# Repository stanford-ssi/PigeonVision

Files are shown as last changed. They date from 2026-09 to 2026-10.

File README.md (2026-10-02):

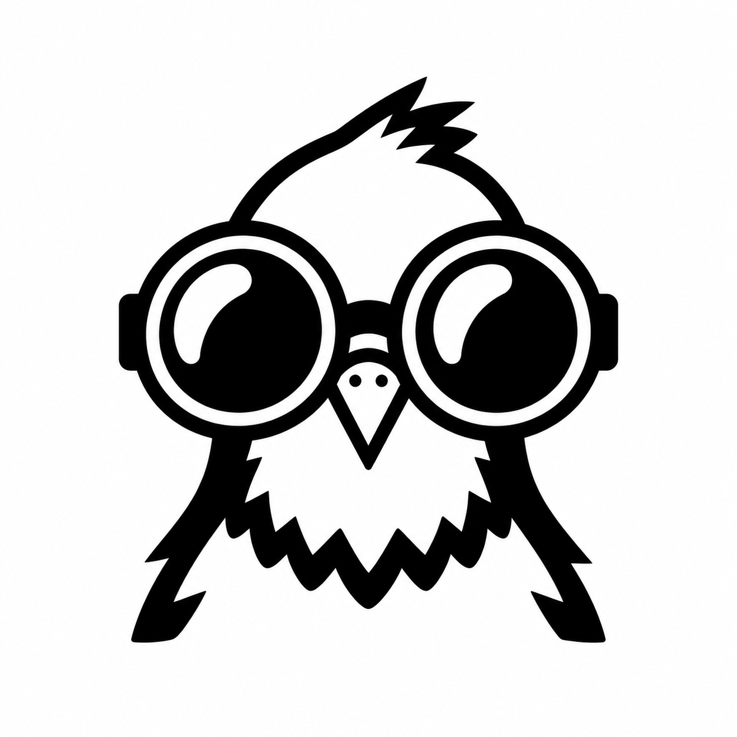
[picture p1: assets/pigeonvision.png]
Pigeon wearing two fisheye camera lenses


# PigeonVision

Video downlink for Stanford SSI's IREC rocket. Two fisheye cameras record the flight and send video to the ground for stitching and viewing.

Try the [flight demo](https://stanford-ssi.github.io/PigeonVision/) to see the camera views and stitched panorama.

**Cur Plan:** two IMX900 cameras at 30 fps, one CM5 and a custom RP2350B transmitter over PV-SPI. E200 remains the fallback. A ground SDR and Linux PC receive and stitch the video. Target: 10,000 ft AGL, 6-inch airframe, 0.5 W average PA output.

- [Hardware](hardware/README.md): system diagram, carrier and RF frontend.
- [Software](software/README.md): flight and ground tasks.
- [Link budget](calculations/link-budget.xlsx): RF and video bitrate calculations.
- [Simulator](docs/README.md): camera views, flight playback and local setup.

**Next:** test autonomous startup and sensor telemetry, then RF. Continue carrier design in parallel.

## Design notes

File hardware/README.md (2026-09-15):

# Hardware

System block diagram

[Edit in draw.io](system.drawio)

| Assembly | Job |
| --- | --- |
| [Carrier](carrier/README.md) | CM5, power, cameras, sensors and service connections. |
| [RF frontend](rf-frontend/README.md) | Attenuation, driver, PA and output filter. |
| Camera adapters, two copies | FRAMOS PixelMate-to-MC50 boards and cables; purchased parts preferred. |
| Flight E200 | DVB-S2 transmitter, mounted above the carrier and connected by Ethernet and SMA coax. |
| Ground E200 | RF receiver connected to the Linux PC over Ethernet. |

**Cur Plan:** KiCad carrier and RF boards, purchased CM5, radios and camera adapters.

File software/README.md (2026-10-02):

# PigeonVision software

The CM5 bench captures both colour IMX900 cameras, records their original video,
and streams to the Mac's interactive A/B and panorama viewer. It uses the official
CM5 IO board, FRAMOS drivers, Ethernet from the Pi, and software x264 encoding.
The Mac currently reaches the LAN over Wi-Fi.

Full 2064×1552 output approached dual 30 fps in short cached-buffer trials; a
later 180-second run still logged five queue drops. The panorama uses measured
lens fits with **nominal** opposed-camera alignment. One-hour performance,
held-out seam accuracy, colour accuracy and exposure synchronization remain
unqualified. See the [bench evidence](bench-notes/2026-09-25.md).

Native SPI is the baseline CM5-to-RP2350B link. The bench uses a Pimoroni Pico
Plus 2 development board; the flight transmitter will use the RP2350B chip.
With a fan, the two-minute test
reached **29.99 fps per camera and 9 Mb/s TS**, with matching Pico counts and
CRC. CPU averaged 61.4%; maximum temperature was 56.75°C. Each camera had one
66.7 ms interval after warm-up. Keep `pv spi` for patterns and file tests.
See [SPI results and setup](flight/spi.md). RF remains untested.

The native service also supports autonomous CM5 acquisition: unique sessions,
independent camera/sensor/UART workers, bounded telemetry and status reporting.
The carrier sensor and UART backends are implemented; their physical wiring,
measurements and FC firmware acceptance remain unverified. Carrier power/reset
sequencing and AFE/LO/PA control have no mapped implementation.

The [startup comparison](bench-notes/flight-startup.json) held dual 30 fps for
two minutes with simulated sensor telemetry over UDP. All 7,201 encoded frames
and 28,206 sensor samples arrived. The new RP2350B startup still needs a SPI run.

## Start here

| Guide | Covers |
| --- | --- |
| [Native capture](flight/README.md) | C++20/libcamera/x264 build, buffers, recording and transport |
| [CM5 → Pico SPI](flight/spi.md) | PV-SPI wiring, sender, backpressure, evidence and viewer copy |
| [Ground app](python/pigeonvision/ground/README.md) | Viewing, replay, E200 receive setup, recording and colour controls |
| [Calibration](calibration/README.md) | Board collection, lens fitting and nominal preview |
| [Shared interfaces](shared/README.md) | Configuration, session/frame records, timestamps and calibration schema |
| [Architecture source](architecture.drawio) | Five editable data-flow and lifecycle pages |
| [Platform pins](platform/versions.json) | Matched OS, kernel and vendor revisions |

Diagram previews: [data flow](diagrams/data-flow.svg),
[CM5 lifecycle](diagrams/cm5-lifecycle.svg),
[sensors and telemetry](diagrams/sensors-telemetry.svg),
[RP2350 lifecycle](diagrams/rp2350-lifecycle.svg),
[startup and shutdown](diagrams/startup-shutdown.svg).

## Provision the CM5

Use Raspberry Pi OS Lite 64-bit **2025-11-24**, kernel
**6.12.47+rpt-rpi-2712**, and the pinned FRAMOS/rpicam-apps stack. Do not run a
distribution upgrade during qualification.
Run provisioning commands from the repository root.

1. Fit `nRPIBOOT` and use the pinned official `usbboot` Linux mass-storage gadget.
   `BCM2712D0 Boot` is the ROM interface, not a disk. Normal imaging needs no
   EEPROM recovery or OTP provisioning.
2. Verify the vendor image SHA-256 and decompress it. Run
   `software/platform/customize_image.py` on the image with the intended **public** SSH key;
   it writes cloud-init, disables password SSH and reports the customized hash.
   Its separate provisioning environment needs `pyfatfs==1.1.0`, `setuptools<81`.
3. Run `software/platform/flash_cm5_macos.py` with explicit disk, USB serial, capacity,
   image hash and new evidence path. It rejects internal/non-USB/non-eMMC targets,
   verifies the write by SHA-256 readback, then ejects. Authenticate on the Mac.
4. After verification/ejection, disconnect power, remove `nRPIBOOT`, connect
   Ethernet and boot normally. Default account: `pigeon@pigeonvision.local`.
   Record `cloud-init status --long`, `uname -a`, board, RAM and storage inventory.
5. Copy the repository to the Pi and run
   `bash software/platform/install_framos.sh`. It holds kernel/firmware packages,
   builds pinned dependencies and backs up/updates boot configuration; it does
   not reboot automatically.
6. Check camera-1 jumpers against the actual IO-board revision, reboot, and run
   `bash software/platform/camera_smoke.sh output/first-cameras`. Inspect both
   cameras' colour, orientation and focus before benchmarking.

Camera auto-detection is disabled; overlays are `fr_imx900,cam0` and
`fr_imx900,cam1-compute`, with vendor FlipY. Recheck GPIO assumptions for a custom
carrier. References: [FRAMOS](https://github.com/framosimaging/framos-rpi-drivers),
[usbboot](https://github.com/raspberrypi/usbboot),
[image customization](https://github.com/raspberrypi/rpi-imager/blob/main/doc/os_customisation_formats.md).

## Build and run

From `software/`, on the Mac and Pi:

```sh
uv sync --locked --extra test
. .venv/bin/activate
pv doctor
```

After installing FRAMOS, build capture **on the Pi**:

```sh
cmake -S flight -B build/flight -DCMAKE_BUILD_TYPE=Release
cmake --build build/flight -j2
ctest --test-dir build/flight --output-on-failure
sudo cmake --install build/flight
sudo ln -sf "$PWD/.venv/bin/pv" /usr/local/bin/pv
pv-capture --list-cameras
```

Replace device placeholders with enumerated IDs and verify their physical A/B
mapping. Use a new session directory for each run. This is the baseline square
profile; set width/height to 2064/1552 for full-sensor output.

```json
{
  "schema_version": 1,
  "session_dir": "output/sessions/bench-001",
  "cameras": [
    {"id": "A", "device": "REPLACE_WITH_CAMERA_A_ID", "flip_y": true},
    {"id": "B", "device": "REPLACE_WITH_CAMERA_B_ID", "flip_y": true}
  ],
  "width": 1552, "height": 1552, "fps": 30,
  "bitrate": 4000000, "vbv_bits": 2000000, "preset": "ultrafast",
  "segment_seconds": 60, "min_free_bytes": 2147483648,
  "record": true, "udp_destination": null, "mux_bitrate": 9000000,
  "duration_seconds": 30
}
```

```sh
pv capture --config capture.json
# Or run the installed remote capture command; config paths then refer to the Pi:
pv capture --config capture.json --ssh pigeon@pigeonvision.local
# Set udp_destination to the Mac's reachable IP:1234, then on the Mac:
pv view udp://0.0.0.0:1234
pv replay path/to/session.ts
```

Use Chrome at `http://127.0.0.1:8768`. Raw views need no calibration; add
`--calibration PATH/calibration.json` for a panorama. The simulator is an explicit
source, never an automatic fallback. See the linked guides for capture options,
received-TS recording and calibration commands.

## Autonomous startup

[Flight and bench profiles](platform/flight/) are configuration templates, not
verified carrier mappings. Flight defaults to full-sensor capture, native 20 MHz
SPI and an I²C backend with no supplied sensor addresses; its camera list is empty
and UART disabled until explicitly configured. See the [native guide](flight/README.md#autonomous-startup-and-status)
for installation and device mapping. Installation preserves deployed configuration
and neither enables nor starts the service. `Restart=no`: a new SPI session requires
coordinated transmitter/link reset; transfer completion is not an RP2350 ACK.

## Benchmark and qualify

```sh
pv bench --config capture.json --output output/bench/matrix-001 --duration 60 --udp MAC_IP:1234 --preset ultrafast --dry-run
pv report output/sessions/bench-001
uv run pytest -q
cmake -S flight -B build/core -DPV_BUILD_CAPTURE=OFF
cmake --build build/core
ctest --test-dir build/core --output-on-failure
```

Compare capture-only, one/two encoders, recording, streaming and combined loads;
then resolutions and presets. Allow a full hour of camera timestamps, not just
process runtime (for example, run 3610 seconds).

Targets remain dual nominal 30 fps with accounted gaps, mean total CPU <80%, no
throttling/undervoltage or growing queues, ≤1 s glass-to-glass latency, recording
through network loss, and readable finalized segments. Calibration targets are
≤1 px held-out RMS and ≤2 px p95, including overlap regions. Free-running cameras
remain unsynchronized until adapter XVS/XHS wiring and levels are verified and
≤100 µs exposure skew is measured optically/electrically. Missing evidence stays
unknown; portable/synthetic tests do not qualify hardware.

Remaining qualification includes physical BMI088/BMP581/INA226 acquisition and
receive-only FC UART; autonomous digital startup and bounded shutdown; cable/attenuator
RF transport; custom-carrier power/reset/GPIO; and storage interruption tests. Keep video independent of
recovery functions. The radio target remains DVB-S2 QPSK 2/3, normal frames,
pilots, 8 MSymbol/s and 9 Mb/s TS; E200 firmware needs hardware qualification.
PA control stays off pending its own authorized procedure. Keep generated
evidence under ignored `output/` directories.

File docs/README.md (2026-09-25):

# Flight camera simulator

Static GitHub Pages site. Open `docs/index.html` through an HTTP server. **Project** links to the repository README.

Two IMX900 cameras sit on opposite sides of a 156.718 mm body. Each CIL212 lens is modeled at an 8 mm pupil offset. The 1552 × 1552 center crops are encoded separately at 30 fps and 4 Mb/s each, then decoded and stitched in the browser. Panning changes viewing direction, not camera position.

The [CIL212 supplier model](https://commonlands.com/pages/camera-field-of-view-calculator) uses `r = 1.1 sin(0.4 θ) / 0.4` mm, with θ in radians. At 2.25 µm pixel pitch, the square crop retains about 197° across each axis and up to 225.8° diagonally. This is predicted coverage, not installed calibration.

The sequence covers the pad, ascent, apogee, separation and early descent. The camera ring is provisionally at the centre of the upper switchband, 0.9024 m from the nose tip; the iris airbrakes sit 150 mm below it. The desert basin is generated terrain, not a survey of the launch site. The 2.9532 m exterior follows the supplied OpenRocket model, including the three fins and boattail. Translation follows the saved M2400T flight (Simulation 5), with a 3 s pad hold and 3,191.207 m apogee. Camera placement, airbrakes and recovery motion remain provisional. Early recovery uses the file’s 0.61 m nominal drogue and 0.30 m shroud lines, with an assumed 80% projected diameter; its 2.1336 m main is specified at 200 m and is not deployed in this short sequence. Lens blur, sensor noise, vibration, attitude errors and RF packet loss are not calibrated or simulated. Synthetic scenery is not a substitute for testing compression on real footage. This does not establish CM5 throughput or radio performance.

The boattail uses the clipped ellipse from OpenRocket. Fin outlines, 7.5 mm thickness and rail-button stations follow the file. Fin edge rounding, fillets, surface finish and camera housings are simplified. Shock-cord lengths and the separation joint need confirmation.

**Controls:** the page opens paused on the pad. Launch starts the sequence; ↺ returns to the pad while keeping the selected projection. Drag to pan, scroll to zoom, or use the direction buttons. With the camera canvas focused, Space toggles playback and comma/period step one frame. Camera crops and the source map show which image supplies each direction. Settings and model notes are below the views.

## Run and check

From the repository root:

```sh
python3 software/simulator/serve.py
```

Open `http://127.0.0.1:8767/docs/`. Browser checks require Node, Playwright and Chrome:

```sh
node software/simulator/check_geometry.mjs
SIM_REQUIRE_ENCODED=1 node software/simulator/check.cjs
```

To regenerate the clips, also install FFmpeg with libx264:

```sh
FFMPEG=/path/to/ffmpeg node software/simulator/render_sequence.cjs
```

Outputs go to `build/simulator/`. Copy both `cil212-camera-*.mp4` files into `docs/assets/video/`, then copy `manifest-v3.json` last. Keep transport streams and logs out of the site. The manifest records settings, source hashes, frame counts and transport timing; mismatched clips fall back to the ideal model.

For Pages, publish the repository's `/docs` directory after merging. All site assets use relative paths; no build service or external CDN is required.

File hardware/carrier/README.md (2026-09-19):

# Carrier

**Cur Plan:** one CM5, two cameras, E200, power and sensors. Record to eMMC; retrieve over Ethernet. No separate MCU.

Carrier block diagram

[Edit in draw.io](block-diagram.drawio)

| Block | Part / connection |
| --- | --- |
| Compute | SC1596 / CM5104064, 4 GB RAM, 64 GB eMMC. |
| CM5 connectors | Two Amphenol 10164227-1001A1RLF, 1.5 mm stack height, matching CM5IO. No components beneath the CM5. |
| Battery input | 3S only, 12.6 V fully charged. Fuse, reverse protection, TVS and input filter. |
| Power | Main 5 V for CM5, E200 and camera regulators; separate RF supply. Filtered sensor branch from CM5_3.3V. |
| Cameras | Two FRAMOS IMX900 modules, CIL212 lenses and FRAMOS FFA-A/MC50 adapters. I-PEX 20525-050E-02 on the carrier. |
| Sensors | BMI088 IMU and BMP581 barometer, shared with Aerolotl. ADXL375 high-g accelerometer optional. Digital power and temperature sensing. |
| Flight UART | Receive-only telemetry; voltage and protocol TBD. |
| Service | USB recovery, boot selector, debug UART, Ethernet and record/shutdown control. No native microSD with the eMMC CM5. |

Include camera level translation, power sequencing and hardware exposure sync.

Top sheet: battery connector and flight UART. Route battery input into Regulators, which contains input protection and the supply circuits. Add regulator subsheets as those circuits are selected.

The CM5 sheet contains two connector symbols and a mounting pattern from the [project library](../libraries/README.md). J1 and J2 each contribute one connector to the assembly BOM. The module itself is installed separately.

Use Aerolotl's sensor parts for simpler sourcing and shared sensor code where practical. Read them directly from CM5. BMI088 gyro range is ±2000°/s (5.56 turns/s); check expected spin before finalizing it. BMP581 covers 300–1250 hPa; revisit its range for a future 30,000 ft flight.

Camera path: PixelMate → purchased FFA-A/MC50 board → MC50 cable → carrier. The [FRAMOS kit](https://www.mouser.com/en/ProductDetail/FRAMOS/FFA-MC50-Kit-0.3m?qs=%252BHhoWzUJg4K3LtaE207mhw%3D%3D) includes both adapters and a 300 mm cable. The carrier replaces the processor-side adapter. Confirm camera screw spacing and cable length before layout.

Mount the bare E200 on standoffs above the carrier. Connect with a short Ethernet cable and a branch from the main regulated 5 V supply. The carrier jack also serves bench access; simultaneous connections need a switch.

Provide rail/enable/reset test points and status LEDs. PA enable defaults off.

Before layout: confirm board outline, mounting holes, camera pinout, rail currents and startup order.

Still to size: power inductors and capacitors, protection FETs, fuse and current shunt. Interface candidates are below; connector choices and the camera GPIO map remain open. The PA and RF filtering remain on the separate RF board.

## Interfaces and protection

Preliminary circuit selection. [Project library and sourcing](../libraries/README.md#camera-interfaces-and-protection). The six semiconductor parts are available for JLC assembly; the EDAC jack is planned for external purchase and hand installation.

| Function | Candidate | Implementation |
| --- | --- | --- |
| Camera I²C | 2 × [TCA9406DCUR](https://www.ti.com/lit/ds/symlink/tca9406.pdf), C840107 | One per camera on separate CM5 buses. Camera side 1.8 V, CM5 side 3.3 V. |
| Camera reset / sync | [SN74AXC4T245PWR](https://www.ti.com/lit/ds/symlink/sn74axc4t245.pdf), C2867798 | Four channels in two direction-controlled pairs. Quantity follows the final GPIO map. |
| Gigabit Ethernet | [EDAC A70-112-331N126](https://www.mouser.com/catalog/specsheets/Edac_12-03-2025_A70_series.pdf), C43709820 | Integrated magnetic RJ45. JLC has no stock; purchase from Mouser and hand-install. |
| Ethernet ESD | 2 × [TPD4EUSB30DQAR](https://www.ti.com/lit/ds/symlink/tpd4eusb30.pdf), C90627 | Eight protected conductors; follow the CM5IO reference circuit. |
| USB recovery ESD | [USBLC6-2SC6](https://www.st.com/resource/en/datasheet/usblc6-2.pdf), C7519 | USB 2.0 D+/D− protection. Check VBUS sensing and avoid powering the carrier from USB. |
| Camera / UART ESD | [TPD4E05U06DQAR](https://www.ti.com/lit/ds/symlink/tpd4e05u06.pdf), C138714 | Low-capacitance candidate for exposed signal connections. Final population follows connector access and signal-integrity review. |
| Battery transient clamp | Littelfuse [SMBJ15CA](https://www.mouser.com/datasheet/2/240/Littelfuse_TVS-Diode_SMBJ-48653.pdf), C78809 | Candidate after the fuse, before reverse protection. Coordinate with input ratings and expected transients. |

MIPI CSI-2 pairs connect directly to the CM5; they do not pass through a GPIO level translator. A four-lane camera plus clock has ten conductors, so protecting all of them takes three four-channel ESD arrays per camera. Keep protection close to the connector with short ground returns; do not add generic high-capacitance TVS parts to these pairs.

TCA9406 has internal 10 kΩ pullups; account for existing board pullups and cable capacitance before adding more. Pull OE low at boot. Its OE input tolerates 5.5 V, so a 3.3 V CM5 GPIO can enable it after the camera rails are valid. Both ports isolate when either supply is at ground.

For SN74AXC4T245, use A = CM5 3.3 V and B = camera 1.8 V. Pull active-low output enables high and camera resets low for safe boot defaults. Fix each channel pair's direction for the chosen camera mode. One IC can carry two resets and two triggers; camera timing outputs need additional channels if used. Its partial-power-down support prevents normal GPIO drive from powering an unpowered camera through this translator.

The CM5 already contains the Ethernet PHY. Use the integrated jack magnetics and the [CM5IO reference wiring](https://pip.raspberrypi.com/categories/1098-design-files); no extra PHY or separate transformer bank. The local EDAC footprint corrects the reference geometry to the manufacturer's drawing. EDAC specifies 0–70 °C operation. No PoE.

Flight UART needs a confirmed logic voltage before selecting translation. If both ends are 3.3 V, use direct logic with connector ESD protection and series-resistor provisions. Keep local sensor buses on the carrier without unnecessary translators.

SMBJ15CA has 15 V standoff and specifies 24.4 V clamping at 24.6 A for the rated pulse. It is not a 15 V clamp or a sustained-overvoltage disconnect. Final input component ratings, fuse and FET selection must account for that clamp and wiring overshoot. Power inductors, capacitors and ferrite values remain for sizing.

## Power plan

**Cur Plan:** one hour on battery. 3S only (12.6 V maximum battery voltage). Battery → fuse / TVS / reverse protection → a main 5 V buck and a separate RF buck. External charging; no USB power sharing in this revision.

These are preliminary parts, not completed circuits. IC current ratings do not establish board-level continuous current capability.

| Circuit | Candidate | Purpose |
| --- | --- | --- |
| Input protection | [LM74502DDFR](https://www.ti.com/product/LM74502), two external N-MOSFETs | Reverse polarity, disconnect, UV/OV thresholds and controlled startup. Fuse remains required; this is not a current-limiting eFuse or reverse-current blocker. |
| Main 5 V | [LM61495RPHR](https://www.ti.com/lit/ds/symlink/lm61495.pdf) | 10 A buck, 3–36 V input. CM5, E200 and camera regulators share a provisional 7 A allocation. Start with 400 kHz; final setpoint and thermal design remain open. |
| E200 branch | Load switch, if independent reset is needed | Powered from main 5 V; no separate E200 converter. |
| RF supply | [TPS62933FDRLR](https://www.ti.com/product/TPS62933F), 5.0 V | 3 A buck, 3.8–30 V input, forced continuous switching. Separate converter, hardware default-off. Allocate 1.5 A initially; measure driver and PA DC current. |
| Camera supplies | Two [TLV75801PDRVR](https://www.ti.com/product/TLV758P) LDOs | Shared 4.0 V from main 5 V; shared 1.8 V from CM5_3.3V. Each LDO is rated 500 mA and has enable and output discharge. Power-cycle both cameras together. |
| Camera reset | CM5 driver and default-low reset circuitry | Software waits at least 200 ms after both rails are valid before releasing reset. No dedicated reset timer in the baseline. Rail ordering and safe boot states remain hardware requirements. |
| Sensors / control | CM5_3.3V; ferrite + local capacitors → SENSOR_3V3 | Budget all external loads within 600 mA, including the camera 1.8 V LDO. Select bead impedance under DC bias, DCR and damping; this is a filtered branch, not another regulator. |
| Battery measurement | [INA226AIDGSR](https://www.ti.com/product/INA226) and Kelvin shunt | Measure protected battery-bus voltage and total current. |

JLC assembly listings: [LM61495 C2943584](https://jlcpcb.com/partdetail/TexasInstruments-LM61495RPHR/C2943584), [LM74502 C3236215](https://jlcpcb.com/partdetail/TexasInstruments-LM74502DDFR/C3236215), [TPS62933F C5219272](https://jlcpcb.com/partdetail/TexasInstruments-TPS62933FDRLR/C5219272), [TLV758 C2876308](https://jlcpcb.com/partdetail/TexasInstruments-TLV75801PDRVR/C2876308), [INA226 C49851](https://jlcpcb.com/partdetail/TexasInstruments-INA226AIDGSR/C49851). All five listed parts were available for assembly when checked; all are Extended parts. Recheck stock and assembly fees with the final BOM. LCSC distributor inventory is separate.

Main-buck sizing: the guide's 70% current rule gives `10 A × 0.70 = 7 A`. The earlier 8 A TPS56837 allows 5.6 A under that rule. At 5 V / 7 A, output power is 35 W; assuming 90–95% efficiency gives 1.8–3.9 W total converter loss. These are design estimates, not measured efficiency or guaranteed board current. Check the inductor against peak current and the converter's current-limit range.

Camera requirements: [FRAMOS sections 5.2–5.4](https://www.mouser.com/catalog/specsheets/FRAMOS_2-12-2026_FSM.GO-IMX900_Datasheet_v1.2a.pdf) specify 3.7–5.1 V on `3V8_VDD`, 1.7–1.9 V on `1V8_VDD`, and 1.8 V control logic. Target 4.0 V for cable/switch drop allowance; verify tolerances at the camera connector. Earlier rail-power figures give preliminary combined loads of 129 mA and 194 mA for two cameras. These are sizing estimates, not measured startup peaks or a guarantee at 4.0 V.

Both cameras share one power sequence and power-cycle together. No per-camera power switches. Keep separate reset signals and power-off-safe control interfaces. Startup: hold both resets low, establish 1.8 V, then 4.0 V, then keep reset low for more than 180 ms after both rails are valid. Use regulator enables where practical; verify output discharge and signal backfeed so a power cycle actually removes camera power. Define shutdown and brownout behavior, with safe hardware defaults during CM5 boot.

Gate camera 4.0 V until 1.8 V is valid. With the preliminary currents above, LDO losses are `(5 − 4) × 0.129 = 0.129 W` and `(3.3 − 1.8) × 0.194 = 0.291 W`. Drawing the 1.8 V rail from main 5 V instead would dissipate 0.621 W in that LDO. Both estimates exclude quiescent current.

Software controls camera reset. Hardware must hold reset low before the driver runs, preserve rail ordering, and prevent control-signal backfeed. The driver must establish rail validity and then wait at least 200 ms before releasing reset, including every power cycle. Brownout handling remains to be defined. A reset supervisor is optional, not part of the baseline.

The [FRAMOS Pi driver inspected](https://github.com/framosimaging/framos-rpi-drivers/blob/c56eef0d232061fa953bccdf514737eeb92e706c/drivers/fr_imx900.c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) toggles its reset GPIO and waits 25–30 ms in `imx900_power_on`; that routine alone does not establish the required 180 ms hold. Its overlay assumes the FRAMOS adapter and must be adapted to our GPIOs and shared supplies.

Selection check: keep LM61495 over [TPS56C215](https://www.ti.com/product/TPS56C215) for its 36 V operating input ceiling versus 17 V, accepting the lower 10 A versus 12 A current rating. Keep TPS62933F for forced continuous switching and adjustable soft start. TLV758 remains suitable if rail timing is established without a PG pin; a PG-equipped LDO is optional. LM74502 remains provisional: retain it for whole-board UV/OV disconnect, or use a PMOS if those functions are provided elsewhere. Neither topology alone replaces the fuse or pack protection.

Battery sizing uses measured average load, not summed converter ratings. Provisional 30–40 W load, 90% overall conversion efficiency and 80% usable battery energy give `Epack = Pload × 1 h / (0.90 × 0.80) = 41.7–55.6 Wh`. At 3.6 V nominal per cell, a 3S 5 Ah pack is 54 Wh: about 58–78 minutes under those assumptions. Use a larger 3S pack if measured draw is near 40 W; 3S 6 Ah is a candidate. Final capacity depends on cells, temperature and discharge cutoff.

At the previous allocations, the main rail needs up to 7 A and RF 1.5 A. At nominal 5 V this is `5 × (7 + 1.5) = 42.5 W`. At 9 V input and 90% efficiency, `Ibat = 42.5 / (9 × 0.90) = 5.25 A`. These are allocations, not measured consumption. Add startup/fault allowance for connector, fuse, FETs and copper. 9 V is a calculation point, not a selected cutoff. A full 3S pack reaches 12.6 V; input transients can exceed it.

Design master, once the Google Sheet exists: **Loads & Runtime**, **Converters**, **Input & Sequencing**. Next calculations are inductor ripple / saturation, capacitor effective capacitance / ripple / inrush, rail voltage tolerances, and losses. For now, keep regulator circuits undrawn until those values are selected.

Next: size the LM61495 divider, inductor and capacitor bank, then the protection FETs and camera sequencing circuit. Keep the imported TPS56837 as an earlier library candidate.

References: [CM5 datasheet](https://datasheets.raspberrypi.com/cm5/cm5-datasheet.pdf), [FRAMOS MC50 mapping](https://docs.framos.com/en/latest/FSMEcosystem/ProductDocumentation/FFA/FFA-MC.html), [BMI088](https://www.bosch-sensortec.com/en/products/motion-sensors/imus/bmi088), [BMP581](https://www.bosch-sensortec.com/en/products/environmental-sensors/pressure-sensors/bmp581).

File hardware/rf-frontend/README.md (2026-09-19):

# RF frontend

**Cur Plan:** 5 V RF board between the E200 and antenna. Target 0.5 W clean average DVB-S2 output at the PA, initially at 1.28 GHz. A 1 dB filter loss leaves about 0.40 W before antenna-cable loss. Frequency TBD.

RF frontend block diagram

[Edit in draw.io](block-diagram.drawio)

| Stage | Part / value |
| --- | --- |
| Input attenuation | Fixed 50-ohm pad, initially 20 dB. Final value from measured gain and waveform peaks. |
| Driver | GRF2011. Reference gain 15.2 dB at 900 MHz, 5 V / 90 mA. Verify at 1.28 GHz. |
| Interstage pad | 3 dB initial. |
| Final PA | GRF5115, 1200-1400 MHz reference tune. At 1300 MHz: 18.6 dB gain and 33.4 dBm P1dB, typical at 5 V. |
| Output filter | LFCN-1500+ low-pass after the final matching and DC block. Add band-pass filtering only if measured spurs require it. |

Gain estimate: `15.2 − 3 + 18.6 = 30.8 dB` before the input pad and other losses. A 20 dB input pad with +10 dBm drive gives about 0.12 W before filtering. Adjust after measurement to reach 0.5 W.

Set usable output from modulation quality, spectrum and receiver performance. P1dB alone does not establish clean DVB-S2 power; filtering cannot repair clipping.

SMA input/output; carrier power, enable and temperature connection. Include default-off enable, separate bias feeds and current test points. Provide heatsink mounting. Driver bypass is an assembly option.

Power filtering: the carrier supplies regulated RF 5 V with its required buck output capacitors. Put the final supply filter, local bulk capacitance and each amplifier's reference bias/bypass network on this RF board. Select series impedance for DC current and voltage drop; check filter damping and PA load transients. Supply filtering is separate from the RF output filter.

Start the schematic and PCB from the manufacturers' band-specific reference circuits, with replaceable input/interstage resistor pads and accessible RF test connections. Check matching, bias, stackup and thermal construction before fabrication. Bench testing sets the final pad values and usable DVB-S2 output power; it is not a prerequisite for starting the design.

A pad is a matched resistor attenuator. The input pad reduces drive; the interstage pad reduces drive and reflections between amplifiers. The shown 20 dB and 3 dB values are starting options. Use the E200's transmit attenuation for routine power adjustment; keep a fixed pad sized for the maximum permitted drive. A separate digital step attenuator is optional if SDR control is insufficient. Its setting, like the SDR setting, does not measure output watts. Verify output power, modulation quality, spectrum and temperature during bring-up.

References: [GRF2011](https://www.guerrilla-rf.com/products/detail/sku/GRF2011), [GRF5115 tune](https://www.guerrilla-rf.com/includes/prodFiles/5115/GRF5115%201200-1400%20MHz.pdf), [GRF5115 datasheet](https://www.guerrilla-rf.com/includes/prodFiles/5115/GRF5115DS.pdf), [LFCN-1500+](https://www.minicircuits.com/pdfs/LFCN-1500%2B.pdf).

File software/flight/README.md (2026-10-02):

# Native CM5 capture

`pv-capture` runs dual IMX900 capture, software x264, segmented recording and
MPEG-TS over UDP or native PV-SPI on the CM5 using FRAMOS libcamera and the Pi ISP. Initial hardware
runs are documented in the [bench notes](../bench-notes/2026-09-25.md);
short-run success is not sustained qualification. There is no synthetic fallback.

## Build and configure

After verifying the FRAMOS kernel/libcamera installation, from the repository
root **on the CM5**:

```sh
sudo apt install cmake g++ pkg-config libavcodec-dev libavformat-dev libavutil-dev nlohmann-json3-dev
cmake -S software/flight -B build/flight -DCMAKE_BUILD_TYPE=Release
cmake --build build/flight -j2
ctest --test-dir build/flight --output-on-failure
build/flight/pv-capture --list-cameras
build/flight/pv-capture --config output/capture-config.json
```

`pkg-config libcamera` must resolve FRAMOS headers/library, version 0.5.2 or
newer. FFmpeg 7+ must provide libx264; the API was checked against 7.1.1.
This build does not install drivers.

See [configuration and artifact contracts](../shared/README.md). `--config -`
accepts stdin; relative `session_dir` resolves against execution CWD, including
SSH. A directory containing only configuration is allowed; an existing session
manifest is refused. Configure zero, one or two cameras; map physical device IDs explicitly to A/B.
Camera initialization failures leave other acquisition paths running.

| Setting | Behavior |
| --- | --- |
| `encode:false, record:false, udp_destination:null` | Capture-only measurement |
| `record:false` with encoding enabled and no UDP | Encoder-only measurement |
| Per-camera `flip_x`, `flip_y` | Defaults false/true for the vendor colour workaround; unsupported transforms fail |
| `encoder_threads` | 1–8 slice threads per camera, default 2 |
| `encoder_input` | `"dmabuf"` default; `"copy"` for the CPU-copy experiment |
| `capture_allocator` | `"libcamera"` default; `"dma_heap_cached"` for imported cached buffers |

Optional shared `camera_controls` supports `exposure_us` plus `analogue_gain`
(both required to disable automatic exposure), `colour_gains:[R,B]` (positive
gains disable AWB), and an optional 3×3 `colour_correction_matrix` with manual
colour gains. Omit the object to preserve vendor defaults. Unknown keys and
incomplete modes fail; each camera's reported limits are checked before capture.
Example: `"camera_controls":{"exposure_us":9993,"analogue_gain":1.0,"colour_gains":[1.64,2.37]}`.
These are experimental settings, not a colour calibration. Per-camera provenance
records requests separately from frame exposure, analogue/digital gain, WB and
CCM; absent effective values remain null. Sensor quantization and ISP saturation
can alter results, including an explicitly requested base CCM. Compare actual
metadata and unclipped images; common requests do not prove matched exposures.
The stock FRAMOS tuning also adapts contrast from each camera's histogram;
manual exposure/WB does not disable that stage. Keep any tuning experiment in
a separate file and record its hash and the startup-confirmed file path.

## Autonomous startup and status

`profile` is `bench` (default) or `flight`. Supply either `session_dir` or
`session_root`; the latter creates `session-` plus 32 random hex digits for each
run, independent of wall-clock availability. Linux takes an exclusive capture
lock before camera initialization; the default is `/run/lock/pv-capture.lock`.
Status defaults to `<session_dir>/status.json`; the flight template explicitly
uses `/run/pv-capture-status.json`. `--status [path]` reads the last atomic
snapshot, defaulting to that deployed flight path when no path is given.
Lifecycle is boot → initializing → running →
stopping → stopped; component state and FC phase are separate fields. Health is
published at 1 Hz; unavailable enabled sensors/UART mark degraded operation. A
normal not-ready poll does not invalidate a recent last-good sensor sample.

After installing `pv-capture`, edit the [flight template](../platform/flight/flight.json)
with verified device IDs and mappings, then install it. Coordinate RP2350/link
reset before starting a new SPI session:

```sh
sudo sh software/platform/flight/install.sh
# Review /etc/pigeonvision/flight.json before explicitly enabling startup:
sudo systemctl enable --now pv-flight.service
pv-capture --status
sudo systemctl stop pv-flight.service
```

The installer preserves an existing configuration and does not enable/start the
service. `Restart=no` is deliberate: every new SPI session requires coordinated
RP2350/link reset. An uncertain SPI transfer latches the transport fault and
returns exit 78 after shutdown; local recording continues meanwhile. Successful
SPI ioctl completion and READY are not receiver acceptance evidence. The service
uses SIGTERM and a 15 s stop timeout; kernel I/O itself is not userspace-bounded.
No carrier rail/reset sequencing or AFE/LO/PA enable is implemented.

## Carrier sensors and FC labels

`sensors.backend` is `disabled`, `simulation` or `i2c`; `flight_uart.backend` is
`disabled`, `simulation` or `serial`. Simulation is explicit and labelled.
Hardware sensor mappings are per-source `device` (`/dev/i2c-N`) and numeric
`address` for `bmi088_accel`, `bmi088_gyro`, `bmp581` and `ina226`. Serial needs an
explicit `device`. Missing mappings report unconfigured/invalid data; no carrier
GPIO, I²C address or UART wiring is inferred. IO-board SPI wiring in the
[SPI guide](spi.md) does not establish a custom-carrier pin map.

The acquisition settings are BMI088 accel/gyro 100 Hz, BMP581 pressure/temperature
25 Hz, and INA226 ready results reported at 10 Hz. Gyro stream FIFO frames share
a host FIFO-read interval; accel/gyro synchronization is not enabled. INA226 uses
16 averages, 1.1 ms bus plus 4.156 ms shunt conversion (84.096 ms per complete
result), calibration 1024 and a 1 mA current LSB, assuming a 5 mΩ shunt. Verify
that shunt on hardware. Bosch driver revisions/licenses are recorded in
[vendor provenance](vendor/PROVENANCE.md). Register readback is not sensor or
carrier qualification.

Local `sensors.jsonl` retains full numerical precision and acquired sample rate.
Downlink groups sensor records every 100 ms into ≤2500-byte column batches,
rounding floating values to six significant digits. Sensor/UART traffic has a
250 kb/s TS budget within the existing 9 Mb/s mux; bounded queues report drops
and stale data. Linux acquisition timestamps use CLOCK_BOOTTIME. Host read
intervals and UART receive times are distinct from physical conversion time and
FC uptime. Missing values remain null. No attitude fusion, ADXL375 acquisition
or flight control is included. The [shared contract](../shared/README.md#carrier-telemetry-and-fc-uart)
defines the UART proposal, pending FC acceptance and electrical verification.

## Sensor mode, rate and timestamps

Capture pins **2064×1552 RAW10** and requests Rec709 YUV420. ISP output selects an
aspect-ratio crop from that mode; square profiles preserve full height before
scaling. Requested and actual crops are recorded. Canonical `sensor_crop` converts
pixel-array ScalerCrop using the selected mode's ScalerCropMaximum origin/scale;
the manifest retains that transform, active areas, physical IDs and orientation.

The pinned driver uses private `Frame rate` control **0x009819b1**, in micro-fps,
with fixed VBLANK. `FrameDurationLimits` alone leaves maximum sensor cadence.
Capture finds the sensor by exact device-tree-node equality with
`/sys/class/video4linux/v4l-subdev*/device/of_node`, verifies FRAMOS compatibility
and the control's ID/name/type/range, writes the requested rate after mode
selection, and reads it back. It then reconfigures the **same mode** to refresh
libcamera/IPA VBLANK, exposure and duration limits. Changed readback or stale
limits fail configuration. `frame_rate_control` records this evidence; verify
actual SensorTimestamp cadence and AE behavior rather than relying on readback.
Relevant pinned source: `fr_imx900.c` rate/control/format functions,
`CameraSensorLegacy::setFormat`, and `CameraData::configureIPA`.

Both cameras share CLOCK_BOOTTIME origin per SensorTimestamp's contract; a
bracketed CLOCK_MONOTONIC sample is also recorded. FRAMOS forwards CFE buffer
timestamps, which do not independently prove the kernel clock domain or exposure
time. Missing, regressing or implausible timestamps are rejected. Prohibit suspend,
verify the target clock, and measure exposure synchronization separately. Sensors
initially free-run; drops retain real timestamp gaps.

## Buffer ownership and allocation experiments

Each camera requests eight buffers and uses a three-frame queue. The completion
callback performs no encoding or disk/network I/O. Reference-counted AVFrames
hold mapped buffers until x264 releases them. Encoding uses no B frames, a
one-second GOP, repeated SPS/PPS and configured bitrate/VBV.

`encoder_input:"copy"` copies active YUV pixels and properties into a reusable
CPU AVFrame with independent padded strides. `av_frame_make_writable` protects
retained FFmpeg references. DMA access ends and capture recycles before encoding.
Health separates copy time from `encoder_input_and_send`, their combined cost;
a shorter send call alone is not faster throughput. Copy mode was slower in the
initial comparison and was not adopted.

`capture_allocator:"dma_heap_cached"` opens only `/dev/dma_heap/vidbuf_cached`;
permission, allocation or import failures have no fallback. Each request receives
one negotiated `frameSize` allocation with one plane at offset zero. Respect
stride/padding: the observed full-sensor layout is stride **2176**, **5065728 bytes**.
The manifest records allocator, heap/resolved target and plane offsets/lengths.
With `encoder_input:"dmabuf"`, leases retain imported buffers without an extra copy;
sensor, crop, colour, timestamps and encoder settings remain unchanged.

CPU reads require `DMA_BUF_IOCTL_SYNC` START/END READ. EINTR/EAGAIN retry at most
16 times with 1 ms backoff; kernel ioctl execution itself has no userspace time
bound. Terminal failures quarantine requests until shutdown. START failure rolls
back successful STARTs; END failure prevents requeue while preserving active
state so shutdown stops the camera. The failure callback cannot throw through
FFmpeg. Health reports `dma_quarantined`, `dma_sync_start` and `dma_sync_end`.
Sync does not replace request-completion and AVFrame lifetime ordering.

Compare equal settings after warmup with repeated controls. Check encoded cadence,
losses, dwell, CPU/temperature, DMA and codec times; decode segments for stale
pixels/stride/colour errors and exercise stop/restart. Initial cached-buffer
results improved throughput, but runtime page attributes and sustained reliability
remain unqualified. Heap backing/import behavior is platform-dependent.

Implementation references: [x264 input copy](https://code.videolan.org/videolan/x264/-/blob/31e19f9/common/frame.c),
[rpicam cached allocation](https://github.com/raspberrypi/rpicam-apps/blob/24906da670e9f2468ac18f2885218b2ba3491a20/core/rpicam_app.cpp),
[PiSP vb2_dma_contig](https://github.com/raspberrypi/linux/blob/stable_20250916/drivers/media/platform/raspberrypi/pisp_be/pisp_be.c),
[FRAMOS buffer import](https://github.com/framosimaging/framos-libcamera/blob/160625a1f0eee5d7522421e0ed52327f35fcbcff/src/libcamera/pipeline/rpi/common/pipeline_base.cpp),
[kernel CPU-sync contract](https://www.kernel.org/doc/html/latest/driver-api/dma-buf.html#cpu-access-to-dma-buffer-objects).

## Recording and transport

Encoded packets feed independent 120-packet recording queues and a 240-item
video transport queue. Telemetry has a separate 64-record queue; transport records
older than 1 s expire. Telemetry loss never resets video keyframe recovery. Recorders rotate at IDRs after the segment duration. Space/write
errors disable recording while transport continues; queue loss is marked at its
actual boundary, skipping dependent frames until an IDR. Sinks have separate drop
counters. Camera/encoder failure stops that camera; the other continues, with no
in-process restart. Both cameras may be absent/failed while telemetry continues.
SIGINT/SIGTERM stops producers and drains work; finalization/log failures
make the exit unsuccessful.

Unknown optional frame controls are omitted from wire JSON when null. Local
frame logs retain them. Queue age is a backlog limit, not a decoder deadline;
`software/tools/check_transport_timing.py` checks a captured TS against PCR/DTS.

One 9 Mb/s TS program uses video PIDs 256/257 and private JSON PID 258; UDP payloads
contain at most seven 188-byte packets. One paced mux owner bounds interleaving;
socket errors do not block capture. The mux's 500 ms decode lead adds **one common
1,000,000 µs PTS offset**, declared in repeated session metadata and subtracted
from both streams by ground. MKV/JSONL retain original capture PTS.

Metadata PES uses producer queue-admission timestamps assigned under its ordering
lock; JSON keeps exact capture `pts_us`. Substituting paced-consumer wall time
feeds backlog into CBR padding. Health records transport queue age, bytes and last
video timestamps; session/geometry metadata repeats each second for late joins.

## Verification

Portable tests need no camera libraries:

```sh
cmake -S software/flight -B build/flight-portable -DPV_BUILD_CAPTURE=OFF
cmake --build build/flight-portable
ctest --test-dir build/flight-portable --output-on-failure
```

With FFmpeg/JSON development packages, `-DPV_BUILD_MEDIA_TESTS=ON` adds
`pv-media-test input-h264.mp4 new-output-directory [storage-floor|transport-failure|cbr-burst]`.
Use `docs/assets/video/cil212-camera-a.mp4`. It exercises actual recorder/TS/UDP
code: PID/frame counts, private JSON, PCR/decode timing, A-stop clock continuity,
IDR segmentation, sink isolation and producer timestamps under encoder bursts.
See [architecture](../architecture.drawio) and its [startup/shutdown preview](../diagrams/startup-shutdown.svg).
It does not qualify acquisition, encoding speed, optics or synchronization.
See the [qualification targets](../README.md#benchmark-and-qualify) for remaining
long-run, latency, power, storage and calibration measurements.

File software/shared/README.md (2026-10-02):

# Capture and ground interfaces (version 1)

These interfaces connect the native capture service, Python bench tools, and browser. All paths are session-relative unless explicitly supplied by an operator. Runtime evidence belongs under ignored `output/` directories.

## Session artifacts

`session.json` identifies `schema_version: 1`, `session_id`, `created_utc`, `clock_origin_ns`, `clock_domain`, `configuration`, `software`, `hardware`, and `calibration` (a bundle path or null). `clock_origin_ns` is sampled from CLOCK_BOOTTIME once before either camera starts, matching the libcamera SensorTimestamp API; record and investigate any platform timestamp-domain discrepancy. Physical libcamera IDs map explicitly to logical `A` and `B` in configuration. Per-camera `flip_x` and `flip_y` select the actual negotiated orientation; the vendor colour baseline uses FlipY.

`frames.jsonl` contains one record per encoded, captured-only or dropped frame: `schema_version`, `camera_id`, `sequence`, `sensor_timestamp_ns`, `pts_us`, `exposure_us`, `analogue_gain`, `status`, and `drop_reason` (null for successful frames). `sequence` is the camera-buffer sequence, not an application counter. Missing sequence records retain null timestamps. Unknown sensor metadata is null, never invented. Encoded timestamps derive from `(sensor_timestamp_ns - clock_origin_ns)` for both cameras; never rebase each camera independently. The sensor timestamp is a reported capture timestamp, not independently verified exposure time. JSONL is the authoritative timing record; MKV/TS timebases can quantize it.

Additive image-control metadata includes `colour_gains` (`[red, blue]` relative to green), `colour_temperature_k`, `colour_correction_matrix` (3×3 row-major), `awb_enabled`, `ae_enabled`, `exposure_time_mode`, `analogue_gain_mode` and `digital_gain`. Missing reports remain null; older recordings may omit these fields. Requested controls are recorded separately in each camera's `colour_control_provenance`: a request is not proof of its applied value. The private transport PID carries frame metadata unchanged.

`health.jsonl` contains native CLOCK_BOOTTIME samples and explicit events, including camera, encoder, recording, transport, queue, CPU, temperature, clock and undervoltage status where available. The optional Python wrapper records its separate CLOCK_MONOTONIC samples in `host-health.jsonl`; clock domains must be retained when aligning them. The native manifest records a BOOTTIME/MONOTONIC bracket. Missing measurements are null. Each camera writes `A-000001.mkv` or `B-000001.mkv` segments with an index describing their common-timeline start and completion state. Camera, recording and transport failures must remain distinguishable.

`sensors.jsonl` stores full-rate `sensor_sample` records plus typed FC status/events.
Local floating values keep full precision; transport rounding is separate. Each
sample records `source`, `backend`, `sequence`, `valid`, `status`, `values`, error
counters and host read interval. On Linux, `host_clock_domain` is CLOCK_BOOTTIME
although legacy field names retain `monotonic_us`, `read_start_monotonic_us` and
`last_good_monotonic_us`. Publication adds session-relative `pts_us`,
`publication_timestamp_ns`, `clock_domain` and `acquisition_clock_domain`.
These times do not prove the physical conversion instant or IMU synchronization.

## Capture executable

`pv-capture --list-cameras` emits JSON camera IDs. `pv-capture --config <configuration.json>`
starts a session and handles SIGINT/SIGTERM shutdown. `--config -` reads stdin;
`--status [path]` reads the last atomic snapshot.

Configuration version 1 has `session_dir`, `cameras` (objects with `id` A/B and `device` libcamera ID), `width`, `height`, `fps`, `bitrate`, `vbv_bits`, `preset`, `segment_seconds`, `min_free_bytes`, `record`, `udp_destination` (null or host:port), `mux_bitrate`, and optional `duration_seconds`. `profile` is `bench` or `flight`. `session_root`
creates a new random session directory instead of a fixed `session_dir`; zero,
one or two configured cameras are supported. Linux `lock_path` prevents concurrent
capture processes; `status_path` reports lifecycle/components independently of FC
phase. The default Linux lock is `/run/lock/pv-capture.lock`; status defaults to
`<session_dir>/status.json`. The flight template selects `/run/pv-capture-status.json`,
which is also the no-argument `--status` lookup path. Use the same capture lock
for every process that owns the real hardware.

`encode: false` selects capture-only measurement and requires recording/UDP/SPI disabled. Defaults: 1552 square, 30 fps, 4000000 bit/s per camera, 2000000-bit VBV, ultrafast, 60-second segments, 2147483648-byte free-space floor, recording enabled, no UDP destination, 9000000 bit/s transport. Camera mode is full 2064x1552 RAW10; derive and report an ISP square crop from actual libcamera pixel-array properties. Never silently accept a narrowed sensor mode.

Optional shared `camera_controls` supports `exposure_us` plus `analogue_gain` together (manual exposure), `colour_gains: [red, blue]` (manual white balance), and `colour_correction_matrix` (requires manual white balance). Omit the object to retain vendor defaults. Empty, unknown or incomplete settings fail; runtime support and limits are checked. Compare per-frame reported controls when evaluating a shared-settings experiment, including any ISP adjustment to the requested matrix. See the [native capture guide](../flight/README.md).

The optional capture setting `encoder_threads` is an integer from 1 through 8, defaulting to 2 per camera encoder. It is retained in the effective session configuration so thread-count experiments can be compared without changing the image profile or other encoder settings.

The optional `encoder_input` setting is exactly `"dmabuf"` (default) or `"copy"`. The default passes mapped libcamera buffers to FFmpeg with their capture leases. `copy` copies active YUV pixels and AVFrame properties into one reusable CPU-allocated AVFrame per camera, respecting independent source/destination strides; it ends DMA CPU access and releases the capture request before encoding. Retained FFmpeg references remain protected through `av_frame_make_writable`. Both modes preserve the sensor mode, image dimensions, crop, PTS, colour and encoder settings. The effective configuration and each camera description record the selected mode. This is an experiment switch, not a claim of faster encoding or a different pixel format.

The independent optional `capture_allocator` setting is exactly `"libcamera"` (default) or `"dma_heap_cached"`. Cached allocation imports one negotiated `frame_size` allocation per request from `/dev/dma_heap/vidbuf_cached`, with no silent fallback. Both paths use the same request ownership, CPU READ sync and AVFrame lease. This setting does not imply an encoder copy; compare it with `encoder_input:"dmabuf"` to isolate allocation. Camera descriptions record `capture_allocator`, nullable `dma_heap_path` / `dma_heap_target`, and `buffer_planes` (one list of `{offset,length}` objects per buffer). Heap selection is recorded evidence, not a measurement of runtime page attributes or performance. No arbitrary heap path is accepted in version 1.

Per-camera health `timing_us` reports cumulative `capture_queue_dwell`, `encoder_send_call`, and `encoder_receive_call` counters, each with `samples`, `total_us`, `mean_us`, `min_us`, and `max_us`. Mean and extrema are null before the first observation. Queue dwell runs from enqueue attempt to normal worker dequeue; rejected frames have no dwell sample. Codec counters time individual FFmpeg calls, including EAGAIN, retries, and flush calls, while excluding subsequent metadata/log/output handling and counter bookkeeping. These are wall-clock call durations, not CPU time or complete per-frame encoding latency.

`encoder_input_copy` measures cached-frame preparation (`make_writable`, pixel and property copy) only in copy mode; its sample count stays zero in dmabuf mode. `encoder_input_and_send` has one sample per frame submission, summing that copy interval and all direct `avcodec_send_frame` intervals for that frame, including a retry after EAGAIN. It excludes flush, receive calls, logging/output handling, DMA synchronization/release, and counter bookkeeping. Compare this combined duration together with encoded cadence, capture losses, queue dwell and CPU usage; a lower send-call duration by itself can merely move work into the copy. These cumulative timing snapshots may straddle an in-flight frame; compare drained session totals or a sufficiently long steady interval.

`dma_sync_start` and `dma_sync_end` measure CPU READ cache synchronization separately from encoder calls. Transient EINTR/EAGAIN errors retry at most 16 times with 1 ms backoff. A terminal sync error sets per-camera `dma_quarantined:true` and `failed:true`, logs `dma_sync_failed`, and prevents further request recycling until the camera stops. The camera retains its buffers, mappings and requests until all encoder references are released and shutdown completes. START/END errors never turn into a successful fallback allocator or permission change.

## Carrier telemetry and FC UART

Backends are explicit: sensors `disabled`/`simulation`/`i2c`, UART
`disabled`/`simulation`/`serial`. I²C mappings supply a device path and address per
source; serial supplies its device path. Configuration and backend labels preserve
provenance. No populated carrier, pin map or physical sensor measurement is implied.

Sensor `values` use SI-named fields: `accel_m_s2[3]`, `gyro_rad_s[3]`, `pressure_pa`,
`temperature_c`, `bus_voltage_v`, `shunt_voltage_v`, `current_a`, `power_w`.
Axes are sensor-native; no rig/body transform is applied. Saturation, FIFO overrun,
pressure range and `power_basis` are reported where applicable. Invalid readings
have `values:null`, never new zero readings. Bosch source revisions are pinned in
[vendor provenance](../flight/vendor/PROVENANCE.md).

Downlink `type:"sensors"` records carry `schema_version:1`, `session_id`, `pts_us`,
`sample_count`, `value_significant_digits:6`, `dropped_samples` and `sources`.
Envelope `backend` and `timestamp_basis` preserve provenance; a source overrides
them only when different. Each source groups rows by validity/status/errors with
`base_monotonic_us`;
row time columns are offsets from that base. Default columns are `sequence`,
`monotonic_us`, `read_start_monotonic_us`, `last_good_monotonic_us`, followed by
source-specific numerical `values.*` columns. Explicit `columns` is retained
when needed. Constant boolean/string values use `shared_values`; absent flags
are not inferred false. Omitted `status` means fresh; omitted `errors` and
`missed_polls` mean zero. Publication is every
100 ms, with ≤2500 bytes per batch, bounded acquisition backlog and transport
loss/rate/expiry counters. Full-precision local JSONL remains independent.

Proposed receive-only FC wire contract (FC firmware acceptance still pending):

```text
PV1,<seq>,<uptime_ms>,<phase>,<event_seq>,<event>*<crc16>\n
```

115200 8N1, no flow control; 3.3 V levels/pins require electrical confirmation.
Maximum 96 bytes including LF; decimal uint32 counters wrap. Phase is UNKNOWN,
PAD, ASCENT, DESCENT or LANDED. Event is NONE, LAUNCH, APOGEE, DEPLOYMENT or
LANDED. CRC-16/CCITT-FALSE covers bytes before `*`: polynomial 0x1021, initial
0xFFFF, no reflection, final XOR zero, four uppercase hexadecimal digits on transmission. Send a 2 Hz
heartbeat and immediate changes; advance `seq` on each frame and `event_seq` on
an event, retaining the latest event in later heartbeats. The receiver emits
`flight_status` and deduplicated `flight_event` records; these are labels only.

At ≥3 s without a valid accepted frame, `valid:false`, `stale:true` and phase
UNKNOWN apply. Bad/duplicate/out-of-order frames do not refresh freshness.
After staleness, two valid progressing frames may establish `inferred_epoch`;
this is conservative reacquisition, not proof of a physical FC reboot. FC uptime
and CM5 receive time remain separate. There is no command/control path.

## Transport and browser

MPEG-TS: video PIDs 256 (A), 257 (B), private data PID 258 (binary private data, stream type 0x06), each private-data PES containing one UTF-8 JSON frame record (or a versioned sensor/FC/health/session record identified by `type`). Metadata PES scheduling uses common-clock producer queue-admission time to keep its single stream monotonic; this timestamp is immutable while queued. Never replace it with the paced consumer's current time: doing so feeds queue delay into CBR null padding and increases latency. The JSON preserves each frame's original `pts_us` and sequence. Budget metadata within the 9000000 bit/s total; additional sensor/UART records
use a 250000 bit/s TS token budget and a separate 64-record queue. Its loss does
not trigger video keyframe recovery. UDP datagrams contain an integral number of 188-byte TS packets, at most seven (1316 bytes). No RTP. Preserve the shared video PTS timeline, with no independent stream rebasing or B frames. Use one-second IDRs with repeated SPS/PPS; recorder segments start on IDRs. PCR is configured for 20 ms and PAT/PMT for 100 ms; verify clock continuity with
one/both cameras absent before treating telemetry-only transport as qualified.

`pv spi --udp 127.0.0.1:1234` consumes this feed unchanged and wraps each group of up to seven TS packets in one fixed 1332-byte PV-SPI v1 transfer. READY gates every transfer; a 16-bit sequence number and IEEE CRC-32 cover the SPI framing. Set capture `udp_destination` to the same local endpoint. `--mirror-udp MAC_IP:1234` sends a raw TS copy after each completed SPI write for the existing ground receiver. This copy does not establish RP2350 acceptance. The sender reports sent-message CRC chain, waits, source/queue losses and unsent data separately from native capture evidence. See the self-contained [SPI interface and bring-up guide](../flight/spi.md).

The native mux applies one common 1,000,000 microsecond PTS offset to both video streams for its 500 ms decoding lead. Repeated session metadata declares `transport_pts_offset_us`; the ground receiver subtracts it before pairing video and capture metadata. JSONL and local Matroska retain original capture PTS. This offset preserves the phase between A and B. Session metadata also carries negotiated geometry, including `sensor_crop` in canonical full-mode coordinates, for calibration compatibility checks.

The Python ground receiver demuxes the same live or recorded TS path with PyAV. Each browser WebSocket binary message comprises a four-byte big-endian JSON-header length, a UTF-8 JSON header, then an Annex-B H.264 access unit. Header fields: `type: "frame"`, `camera_id`, `timestamp_us`, `keyframe`, `codec` (RFC 6381 AVC codec string derived from SPS). Key access units include SPS/PPS. WebSocket text messages carry typed `status`, `metadata`, `calibration`, and `error` JSON objects. Ground accepts metadata-only TS sources and displays telemetry/phase freshness.
Ground playback control and configuration are separate from flight control.

Each browser decoder retains original timestamps. Queue bounds and stale/missing cameras are explicit. Synthetic media is an explicit source, never an automatic fallback. Ground routes and CLI integration live in `pigeonvision.ground`.

`pv-flight.service` uses `Restart=no`. A new SPI session needs coordinated
RP2350/link reset; uncertain native SPI transfers latch the transport failure and
produce exit 78 after shutdown. READY is buffer credit and a completed ioctl is
not an acceptance ACK. Carrier power sequencing and PA control remain unmapped.
See the [architecture source](../architecture.drawio) and
[startup/shutdown preview](../diagrams/startup-shutdown.svg).

## Calibration

`calibration.json` contains `schema_version: 1`, `model: "mei"`, `cameras` keyed by A/B, and validation evidence. Each camera has `image_size: [width,height]` for the canonical unflipped full sensor, `K` (3x3), `D` (four Mei radial/tangential distortion coefficients), `xi`, `R_camera_from_rig` (3x3), `crop: [x,y,width,height]`, `output_size`, `flip_x`, `flip_y`, and `valid_radius_px` (null if no circular mask was measured; otherwise centred on K's principal point in full-sensor pixels). Fitting observations are unflipped using explicit dataset orientation. Projection: rotate the rig ray; normalize it; use x/(z+xi), y/(z+xi), then radial/tangential distortion, K, crop, pixel-centre scaling `(u-x+0.5)*scale-0.5`, and flips. Reject z+xi<=0 and, when xi>1, z<=-1/xi; also apply measured angular coverage and image masks. This is an infinity projection; near-field parallax is not corrected.

Calibration utilities must distinguish fitting observations from held-out validation, preserve rejected observations and report error by image region and seam overlap. Lack of real calibration is an explicit uncalibrated state, never a fabricated successful calibration.

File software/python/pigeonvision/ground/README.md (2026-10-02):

# Ground receiver

The ground station receives both camera streams, presents a full-bleed video
view with mission telemetry, and records/replays received transport. It uses PyAV,
WebSockets, WebCodecs and WebGL2 with the
[version 1 contracts](../../../shared/README.md). Controls change the ground
presentation and playback; there is no flight-control endpoint.

From the repository root after installing the Python package:

```sh
pv view udp://0.0.0.0:5000 --record-transport output/session/transport.ts
pv replay output/session/transport.ts --calibration output/calibration/calibration.json
python -m pigeonvision.ground output/session/transport.ts --calibration output/calibration/calibration.json
```

Open `http://127.0.0.1:8768/` in desktop Chrome. Python API:
`pigeonvision.ground.run(source, host="127.0.0.1", port=8768, calibration=None, open_browser=True, replay=None, record_transport=None)`.
`replay=None` distinguishes files from UDP URLs; the async app factory is
`pigeonvision.ground.server.create_app`.

## Radio input

The primary field computer is the M4 Pro MacBook: radio decoding, viewing,
recording and broadcast. Keep Linux compatible without requiring a desktop or
RTX 3070. GNU Radio runs separately in its own environment; radio reception and
full-rate decoding remain untested. Upscaling and frame interpolation are
optional later work, subject to measured laptop headroom.

```text
Ground antenna → E200 RX1 → wired Gigabit Ethernet → ground computer
  gr-dvbs2rx → TSDuck → UDP :5000 → PigeonVision viewer / recording
```

Use the E200's Pluto/IIO firmware. USB-C provides serial maintenance; Ethernet
carries I/Q. Its documented default address is `192.168.1.10`; a direct-connected
computer can use an otherwise unused `192.168.1.100/24` Ethernet interface. A
MacBook needs a USB-C/Thunderbolt Gigabit Ethernet adapter.

| Setting | Baseline |
| --- | --- |
| Waveform | DVB-S2 CCM, single stream, QPSK 2/3 |
| Frames | Normal, pilots on, Gold code 0 |
| Symbol rate / roll-off | 8 Msymbol/s / 0.20 |
| Nominal occupied bandwidth | 9.6 MHz |
| E200 receive sampling | 16 Mcomplex samples/s |
| Transport | 9 Mb/s TS; A/B video PIDs 256/257, JSON PID 258 |

I/Q alone uses `16e6 × 2 × 16 = 512 Mb/s` before network overhead. The nominal
9.6 MHz waveform fits the AD9363 model's 20 MHz analog bandwidth. Sustained IIO
transfer and CPU decoding still need measurement; neither proves RF link margin.

The launcher targets [gr-dvbs2rx](https://github.com/igorauad/gr-dvbs2rx/tree/130c31576cfeebb1a5842b24ccaf4a561b6a9990)
at `130c31576cfeebb1a5842b24ccaf4a561b6a9990`, GNU Radio 3.10 with
`gnuradio.iio.fmcomms2_source_fc32`, compatible libiio/libad9361, and
[TSDuck](https://tsduck.io/). The receiver also imports PyQt5 and GNU Radio UHD.
Keep its Python installation separate from the viewer's virtual environment.
Use [conda-forge GNU Radio](https://github.com/conda-forge/gnuradio-feedstock/blob/main/recipe/meta.yaml)
as the common dependency route: its IIO packages cover Linux and native Apple
Silicon. Stock Homebrew GNU Radio omits IIO. Apply
[`gr-dvbs2rx-arm64.patch`](../../../platform/gr-dvbs2rx-arm64.patch) to the pinned
receiver source before building; it removes a 32-bit-only compiler flag on
Apple's `arm64` target while retaining NEON. Patch application was checked;
the complete environments and receiver builds remain unverified.

From the repository root, start the viewer, then receive in a second terminal:

```sh
pv view udp://127.0.0.1:5000 --record-transport output/radio-001/transport.ts \
  --calibration software/calibration/bench-2026-10-02/calibration.json
RX_FREQ_HZ=REPLACE_WITH_BENCH_FREQUENCY_IN_HZ
bash software/tools/e200_receive.sh "$RX_FREQ_HZ"
```

Use a new recording path each run. `E200_URI`, `RX_GAIN_DB` and `TS_DEST` override
the launcher defaults; append `--dry-run` to inspect commands. Gain starts at
0 dB for bench setup and must be adjusted to the received signal. TSDuck forwards
seven original TS packets per UDP datagram without transcoding or removing
telemetry. Initial preload and input batches are seven packets to avoid the
default multi-megabyte startup buffer. Receiver diagnostics stay on stderr.

Next: decode a bounded RP2350 reference waveform offline, then measure real-time
decoding on the MacBook. When the E200 arrives, check sustained 16 MS/s IIO
capture before adding decoding, viewing and recording. RF lock/SNR/FEC status
still needs integration into the viewer; the current HUD only knows TS health.

References: [E200 setup](https://antsdr-docs.microphase.cn/en/latest/device_and_usage_manual/ANTSDR_E_Series_Module/ANTSDR_E200_Reference_Manual/AntsdrE200_Unpacking_examination.html),
[receiver installation](https://igorauad.github.io/gr-dvbs2rx/docs/installation.html),
[receiver interfaces](https://igorauad.github.io/gr-dvbs2rx/docs/usage.html).

## Operator and audience

`/` is the operator view; `/?mode=audience` follows the shared presentation with
the drawer hidden. Both show source failures, held video and unavailable telemetry.
The first operator receives control. Other operators follow until selecting
**Take control** in the bottom toolbar; audience viewers cannot claim control. Ownership coordinates
trusted local viewers and is not authentication.

Open **Controls** to select raw A/B, panorama or look-around views, manage replay,
set a pad reference and inspect diagnostics. Focus the image for shortcuts:

| Input | Action |
| --- | --- |
| WASD / arrow keys | Pan continuously in look-around mode |
| Q / E | Roll the look-around view left / right |
| Shift while panning | Fine movement |
| Drag / wheel | Pan / zoom the current view |
| 1–9 / preset button | Recall a view |
| Shift+1–9 / Shift-click | Save direction, roll, FOV and reference frame |
| Space / period | Replay play-pause / step pair |

Presets and **Use as default** FOV are stored per browser; unavailable storage
keeps changes within the page. The direction ribbon is body-relative: A is 0°,
B is 180°, with positive pitch looking up. It is not a geographic heading.
The view follows the camera rig by default. **Level horizon** uses the demo's
exact scene orientation at the displayed pair's timestamp. It is optional and
unavailable for real footage until timed attitude estimation is implemented.
Missing orientation stops compensation and shows an unavailable state. In level
mode the direction ribbon uses the scene reference, not camera A/B bearings.
Q/E adds manual roll; neither option changes the recorded images.

## Received-transport recording

`--record-transport` saves each UDP payload exactly once before demux, including
video, private JSON and received damaged packets. Upstream loss remains present.
Both the output and `.recording.json` evidence path must be new; the option
requires live UDP and persists through demux reconnects.

A bounded 512-datagram writer queue isolates reception from disk writes. Overflow
or disk errors disable recording while live viewing continues. Browser status
and `/health` expose `transport_recording` state, bytes and errors. Normal shutdown
drains accepted bytes, fsyncs/closes, then records size, SHA-256 and completion.
Hard termination leaves the evidence marked `recording`, not complete.
Direct replay of paired native MKVs still needs a future remux/import command.

## Views and calibration

Saved TS opens paused with one pair loaded. Play/Pause/Step pair/Restart share one
server timeline. Opening or reconnecting another viewer loads cached decode
history and the held frame without restarting, resuming or advancing established
playback. Replay pauses when the final viewer disconnects. Raw A/B views work
without calibration; panorama, perspective and coverage views require a Mei
bundle. Missing cameras never become simulator imagery.

In raw views, use the 1–8× slider or wheel to zoom and drag to pan. At 1× the full
transmitted rectangle fits. `Reset view` resets that camera's zoom/centre but
preserves its independent `Rotate 180°` toggle. These display settings are shared
with following viewers and do not change recordings or calibrated geometry;
zoom cannot recover cropped pixels.

Projection uses canonical full-sensor pixel centres, then crop/scale
`(u-crop_x+0.5)*scale-0.5` and output flips. Rig axes are +Z through A, +X right,
+Y down; the Mei `xi>1` second branch is rejected. Optional `max_theta_deg` bounds
observed coverage; absent limits stay unvalidated. See the shared contract for
masks and rotation fields.

Runtime device IDs, flips, sensor mode, output dimensions and canonical
`sensor_crop` must match the bundle. Mismatches disable panoramas; missing
evidence is shown as unverified. Raw `scaler_crop` needs the native origin/scale
conversion. Importing a bundle does not certify alignment, lens retention,
edge quality or synchronized exposures.

## Preview colour balance

Optional `display_colour` uses these fields:

| Field | Requirement |
| --- | --- |
| `schema_version`, `method` | `1`, `"display_rgb_gain"` |
| `gains`, `devices` | A/B RGB triples, finite 0.5–2; IDs match lens provenance |
| `reference_camera` | A or B, retaining identity gains; or `null` with `reference_target: "colorchecker_neutrals"` or `"measured_neutral_surfaces"` |
| `camera_strengths` | Optional initial A/B strengths, each 0–1 |
| `common_headroom_scale` | Optional 0.5–1 for a neutral target; camera reference requires 1 |

The shader applies gains to decoded display RGB before blending. This is not a
linear-light colour calibration: [WebCodecs may convert colour space](https://www.w3.org/TR/webcodecs/#video-frame-rendering).
Retain source frames, lighting, fit/check evidence and limitations with the profile.

Independent A/B strength sliders use `scale + strength*(gain-scale)`: 0% removes
balance while retaining common dimming. The original-colour toggle bypasses
both. Choices survive WebSocket reconnects within the page. Missing or mismatched
identity/orientation/crop gates correction. During metadata recovery, the last
verified corrected image is held until new frames can be verified. Held video is
labeled and cannot advance telemetry. Explicit camera or crop mismatches still
disable correction. Recorded pixels and camera controls do not change.

Measure unclipped neutral patches, check other frames and remeasure after
lighting or ISP changes. Neutral balance does not establish absolute colour or
exposure matching; see [ColorChecker guidance](https://calibrite.com/us/product/colorchecker-classic/?noredirect=en-US).

## Timing, recovery and APIs

PIDs 256/257 carry A/B; 258 carries JSON. The declared common
`transport_pts_offset_us` is subtracted once from both videos, preserving their
relative timing; undeclared transports use zero. A late declaration resets both
decoders. Native session metadata repeats for late joins.

TS continuity gaps, corruption, backward timestamps and queue overflow trigger
explicit IDR recovery. Bounds include 48 receiver messages, browser ingress and
decoder queues, and six pairing frames per camera. Live source failures reconnect;
stopped cameras display held/stale states.

`/ws?role=operator` or `/ws?role=audience` carries Annex-B access-unit envelopes and
typed status/metadata/calibration/error messages, plus ground view, ownership and
reference updates. The active operator's saved-source controls are JSON
`{"type":"control","action":"play"}`, also accepting `pause`, `step`, `restart`.
`/health` exposes counters and first-access-unit delay, which is neither
exposure skew nor glass-to-glass latency. Shutdown closes WebSockets before
waiting for handlers, then finalizes the receiver and transport recording.

## Mission telemetry

The HUD consumes transported BMP581 pressure and flight status/events. Sensor
measurements use acquisition timestamps aligned to the displayed video PTS;
future measurements and events are excluded. Legacy flight records or individual
sensor samples without acquisition fields use their declared publication PTS.
Raw sensor and flight diagnostics remain in the drawer.

While phase is `PAD` and pressure is fresh, the operator can **Set barometric
zero**. `BARO AGL` estimates height above that pad pressure using the standard
atmosphere, `44330 * (1 - (pressure / pad_pressure)^0.190263)` metres. It does not
measure terrain clearance. `BARO VERTICAL SPEED` is a least-squares altitude
slope over the last second, requiring four samples spanning at least 0.5 seconds;
invalid readings or gaps above 250 ms suppress the slope.

Pressure expires after 0.5 seconds at the displayed PTS, phase after 3 seconds;
live pressure and phase also expire after 3 seconds without receipt. Missing, invalid or
stale values show `—`, and unavailable phase shows `UNKNOWN`. The altitude plot
breaks acquisition gaps and invalid samples. `T+ (FC RX)` and event times use the
CM5 receipt time of the flight-controller event, not physical ignition time.
`LIVE`/`REPLAY` identify the source mode; simulated inputs retain `SIMULATED`.

## Broadcast and demo

Use a fullscreen Chrome audience window and an OBS **Window Capture** of that
window, with the operator window outside the capture. HDMI/SRT handoff remains
TBD. A standalone native GPU renderer is an optional later enhancement and is
not implemented. Projection, HUD and preview colour operate on the ground
display; the original TS stays unmodified.

Generate the synthetic demo from the repository root, then open its saved replay:

```sh
python software/tools/ground_demo.py
pv replay build/ground-station/demo/launch.ts --calibration build/ground-station/demo/calibration.json
```

The generator writes both files under `build/ground-station/demo/`. Its synthetic
video and telemetry are labeled `SIMULATED`.

For the full saved OpenRocket flight, prepare a separate capture site and serve it:

```sh
python software/tools/full_flight.py path/to/rocket.ork --prepare-site
python -m http.server 8774 --bind 127.0.0.1 --directory build/ground-station/full-flight/site
```

In another terminal, with Chrome, Playwright and FFmpeg available:

```sh
SIM_SITE_DIR=build/ground-station/full-flight/site \
SIM_OUTPUT_DIR=build/ground-station/full-flight/video \
SIM_URL='http://127.0.0.1:8774/?capture=1' node software/simulator/render_sequence.cjs
python software/tools/ground_demo.py \
  --source-manifest build/ground-station/full-flight/video/manifest-v3.json \
  --trajectory build/ground-station/full-flight/site/assets/launch.json \
  --output build/ground-station/full-flight/demo
pv replay build/ground-station/full-flight/demo/launch.ts \
  --calibration build/ground-station/full-flight/demo/calibration.json
```

This uses the file's saved trajectory through landing. Recovery swing, impact
pose and terrain remain illustrative. One effective canopy changes size for
main deployment; it does not reproduce the real two-canopy rigging.

## Verification

Python tests cover real mux/demux, timestamps, UDP/HTTP/WebSockets, shutdown,
continuity recovery, byte-exact recording and failure isolation. Projection tests
compare against OpenCV. Run them from `software/` with `uv run pytest -q`.

Browser checks use Chrome/Playwright. `test_ground_browser.cjs` and
`test_ground_shader.cjs` need a local test viewer. The focus, layout, colour-app
and telemetry browser tests route local assets with mocked WebSockets.
`test_ground_focus.cjs`, `test_ground_errors.cjs`, `test_ground_mission.cjs` and
`test_ground_navigation.cjs` run offline in Node. Fixtures are synthetic;
these checks do not qualify real optics or hardware.

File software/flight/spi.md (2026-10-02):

# CM5 → RP2350B SPI

Baseline: native `pv-capture` → 20 MHz SPI → RP2350B PIO receiver. The RP2350B
owns its output clock and inserts null packets below capacity. Bench wiring below
uses a Pimoroni Pico Plus 2 development board. RF remains untested.

## Camera output

Add these settings to the camera config:

```json
{
  "capture_allocator": "dma_heap_cached",
  "encoder_input": "dmabuf",
  "encoder_threads": 3,
  "udp_destination": null,
  "mux_bitrate": 9000000,
  "spi": {"device": "/dev/spidev0.0", "hz": 20000000, "ready_line": 25}
}
```

Start a fresh Pico `pvtx` run first, then `pv-capture --config capture.json`.
SPI0 must be enabled (`dtparam=spi=on`) and the user needs SPI/GPIO access.
Native output uses Linux spidev and GPIO v2, with no Python SPI packages.
Omit `spi` to use UDP; the two outputs are mutually exclusive.
`spi.gpiochip` can select the RP1 device explicitly; otherwise it is discovered.

The bounded transport queue keeps SPI from blocking capture or recording.
READY low for two seconds stops transport. Failed or short writes are not
retried. Compare final `outputs.transport.spi` counts and CRC with the Pico
report. SPI has no acknowledgment.

## Bench result

Two IMX900s at 2064×1552, 4 Mb/s each, simultaneous recording, with a fan:

| 120-second run | Measured |
| --- | ---: |
| Encoded rate A / B | 29.99 / 29.99 fps |
| MPEG-TS rate | 9.0006 Mb/s |
| Average CPU, all four cores | 61.4% |
| Maximum temperature | 56.75°C |
| Accepted SPI messages | 102,801 |
| Matching CRC chain | `0x0f20927e` |

No transport loss, Pico protocol errors or underruns were observed. Each camera
had one startup error and one 66.7 ms interval after warm-up. The optimized
Python bridge used 78.8% CPU and delivered 29.78/29.80 fps in its 60-second run.
These are bench measurements with airflow, not passive-cooling or RF results.

[Raw results and reproduction commands](https://github.com/Rivercraft911/RP2350_IQ_Benchmark/tree/main/results/cm5-spi).

## Startup changes

The RP2350 repository adds a separate `pvflight` build: stored modem preset,
autonomous digital output, then READY. The existing `iqbench`/`pvtx` bench path
remains available. USB `status` and `stop` work during flight output; a new CM5
SPI session still requires a coordinated transmitter restart.

The [supervisor comparison](../bench-notes/flight-startup.json) uses real cameras
and simulated carrier/FC data over UDP, not SPI. The final 120-second run delivered
30 fps per camera, all 7,201 encoded frames and all 28,206 sensor samples. No
transport drops, continuity errors or late video packets occurred; minimum
video DTS-to-PCR margin was 245 ms. Two startup camera errors remain, one per camera.

An initial 500 ms queue expiry dropped valid bursts. The final build omits null
frame fields on the wire and uses a 1 s queue age limit; measured maximum queue
age was 433 ms. Full metadata stays in local logs. CPU was 62.9%, including the
extra UDP capture process; maximum temperature was 63.9°C with no throttling.
Next hardware check: repeat the two-minute SPI/CRC comparison with `pvflight`.
Physical carrier sensors, autonomous RP2350B timing and RF remain unverified.

## Wiring

3.3 V signals. Physical pins refer to the CM5 IO-board and Pico Plus 2 headers.
The final carrier assignment is separate.

| Signal | CM5 GPIO / physical pin | Pico GP / physical pin | Direction |
| --- | --- | --- | --- |
| SCK | GPIO11 / 23 | GP17 / 22 | CM5 → Pico |
| MOSI | GPIO10 / 19 | GP18 / 24 | CM5 → Pico |
| CS_N | GPIO8 / 24 | GP19 / 25 | CM5 → Pico |
| READY | GPIO25 / 22 | GP22 / 29 | Pico → CM5 |
| GND | 20 or 25 | 23 or 28 | Common ground |

MISO is unused. Fit a 4.7 kΩ pull-up to Pico 3.3 V on CS_N and a 4.7–6.8 kΩ
pull-down to GND on READY. Power Pico before CM5 drives SPI. Keep bench jumpers
short, with ground beside SCK, and check pin ownership against camera overlays.
Never enable Pico SPI self-test while the CM5 is wired to these pins.

## PV-SPI v1

Mode 0, MSB first, 8-bit words. One **1332-byte transfer per CS_N assertion**.
CS_N stays high ≥10 µs before checking READY for the next transfer. READY must
be high before every transfer. All multibyte fields are little-endian.

| Offset | Bytes | Field |
| --- | --- | --- |
| 0 | 2 | Magic `0x5650`, wire bytes `50 56` |
| 2 | 1 | Version 1 |
| 3 | 1 | Type 1: TS_DATA; type 0: empty NOP |
| 4 | 2 | Sequence, modulo 65536 |
| 6 | 2 | Payload length: 188 × n, n=1…7; NOP length 0 |
| 8 | 4 | Reserved, zero |
| 12 | 1316 | TS packets beginning with `0x47`, then zero padding |
| 1328 | 4 | IEEE reflected CRC-32 over bytes 0…1327 |

CRC init/final XOR: `0xFFFFFFFF`; `crc32("123456789") = 0xCBF43926`.
`pv spi --vector` produces CRC `0x51be328d` without hardware. File tails,
malformed UDP and invalid TS sync are errors. USB starts/configures `iqbench`;
the separate `pvflight` build starts automatically.
Use a fresh receiver run for each sender, which starts at sequence zero.

The Pico report must match sent messages, TS packets, bytes and the CRC chain,
with zero protocol errors or underruns. Let its output drain before its command
expires. Check physical timing on the final wiring and repeat with RF operating.

[Protocol specification](https://github.com/Rivercraft911/RP2350_IQ_Benchmark/blob/main/docs/pv-spi-spec.md).

## Why SPI

At 9 Mb/s TS, framing needs `9 × 1332 / 1316 = 9.11 Mb/s` on the wire.
At 20 MHz that is **46.4% bus time**, including minimum CS gaps, before Linux
scheduling delays. This is not a measured maximum throughput. The current
8 Msym/s QPSK 2/3 pipeline accepts about **10.33 Mb/s TS**.

RS-485 is useful for a longer, noisy cable. With UART 8N1, the same data needs
at least `9.11 × 10/8 = 11.39 Mbaud`, plus flow control. Fast transceivers exist,
but this needs a different Pico receiver. Pico USB is 12 Mb/s full-speed before
overhead. Neither offers a clear advantage for the nearby transmitter board.

Sources: [TI RS-485 guide](https://www.ti.com/lit/an/slla272d/slla272d.pdf),
[RP2350 datasheet, UART §12.1.3.1 and USB §12.7.1.1.1](https://datasheets.raspberrypi.com/rp2350/rp2350-datasheet.pdf).

## Python test sender

Keep `pv spi` for patterns, files and comparisons. From `software/`:

```sh
uv sync --locked --extra spi
. .venv/bin/activate
pv spi --pattern --count 10000 --hz 1e6 --summary output/pattern.json
```

Start the Pico first, and test increasing clocks before 20 MHz. The Python
sender defaults to 1 MHz and a one-second READY timeout. For a live comparison,
use UDP output in the capture config, omit `spi`, then start the bridge before
capture:

```sh
sudo /usr/sbin/sysctl -w net.core.rmem_max=4194304
pv spi --udp 127.0.0.1:1234 --hz 20e6 --transfer tx-only --udp-mode direct \
  --ready-timeout 2 --idle-timeout 15 --duration 130 --summary output/bridge.json
```

Give the bridge time to drain after capture stops. Check its final status,
unsent data and UDP drops as well as the Pico counters. `--mirror-udp IP:PORT`
adds a preview copy, but does not prove Pico acceptance and was disabled in
the comparison runs.

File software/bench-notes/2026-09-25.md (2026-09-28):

# First CM5 camera bench

This is a bring-up record, not a qualification report. Generated evidence is kept
under the ignored `output/` directory on the Mac and CM5.

## Hardware and platform

- CM5: 4 GiB RAM, 64 GB eMMC; official CM5 IO board.
- Two colour IMX900 modules; A is the `i2c@88000` camera path (CAM0), B is
  `i2c@70000` (CAM1). Both J6 camera-1 jumpers are now fitted. The nRPIBOOT
  provisioning jumper is removed.
- Lenses were selected as CIL212; physical markings and adapter revisions still
  need to be recorded. The operator judged focus sufficient for the initial demo
  and mounted both cameras in the printed rocket on September 25.
- Power is from the Mac USB-C connection. The CM5 has a passive cooler. The
  operator subsequently turned on an external fan; the later temperature drop
  must not be attributed to the passive cooler alone.
- CM5 Ethernet negotiates 1 Gb/s. The Mac currently reaches the LAN through
  Wi-Fi, so this is not a wholly wired transport qualification.
- Raspberry Pi OS Lite 64-bit, 2025-11-24, kernel
  `6.12.47+rpt-rpi-2712`, with the FRAMOS pins in `platform/versions.json`.
  Imaging was verified by byte readback. SSH uses keys for account `pigeon`;
  an empty password is not a login method.

## Measured results and fixes

1. Both cameras produced individual and simultaneous 2064×1552 JPEG images.
   The still and preview modes both need the full RAW10 sensor mode. The default
   smaller preview mode caused a format mismatch during the first attempt.
2. Requesting standard libcamera frame-duration limits initially left the sensor
   near 87 fps. The pinned FRAMOS driver requires its private frame-rate control,
   followed by a same-mode reconfiguration to refresh libcamera's exposure
   limits. Both sensors then reported 30,000,000 micro-fps and 33,333 µs frame
   duration limits.
3. In the first one-minute square-output recording, each camera produced 1,793
   encoded frames and eight explicitly recorded startup frame errors. Steady
   capture intervals were approximately 30 fps. Mean total CPU use was 50.75%,
   maximum logged temperature was 58.4°C, and throttle flags remained zero.
   Both finalized MKV files decoded with the expected frame counts. This is not
   the one-hour qualification, and this earlier run does not establish the
   cooling state of every later run.
4. A later stream developed seconds of delay. Metadata timestamps sampled inside
   the paced transport consumer advanced the mux clock ahead of queued video,
   creating unnecessary padding and further backlog. Stamping queue admission
   at the producer removed that feedback. A repeat receiver-age check fell from
   roughly 3.3 seconds to 0.43–0.64 seconds. These estimates include sequential
   SSH sampling overhead and exclude browser presentation; they are not a
   glass-to-glass latency measurement.
5. The operator reported clipped image sides and a tint difference. The square
   output's measured sensor crop is `[256, 0, 1552, 1552]`: it discards 256 sensor
   columns on each side. A full 2064×1552 diagnostic was started to examine the
   mounted lens coverage. A full sensor view cannot recover light that falls
   outside the physical sensor. Colour mismatch remains unqualified; the
   cameras have independent automatic white balance.
6. The `dual-fullsensor-002` frame metadata confirms both cameras use canonical
   crop `[0, 0, 2064, 1552]`, with no extra vertical crop. The Mac decoded both
   streams at 2064×1552. Saved frames show the image circle crossing the top and
   bottom sensor edges. Full-sensor encoding has logged additional queue drops;
   throughput is not yet qualified. The earlier `dual-fullsensor-001` interval
   also contained a native compilation workload and is unsuitable for an
   uncontaminated encoder comparison.
7. Colour telemetry was built and tested on the CM5 (three native checks), then
   verified in actual frame records. An early pair reported red/blue gains
   approximately `[1.611, 2.418]` for A and `[1.662, 2.326]` for B, at 3935 K and
   3970 K respectively. The cameras also report differing correction matrices.
   These readings establish that processing differs; they do not establish
   which camera is more accurate or isolate illumination from camera response.
   `awb_enabled` is unreported and remains null. No manual colour override has
   been applied.
8. Clean full-sensor thread comparisons did not reach 30 encoded fps per camera.
   With three encoder threads per camera, the measured rates were 29.12 fps for
   A and 29.40 fps for B; with four they were 28.94 and 29.33 fps. Both sensors
   continued near 30 fps. The roughly 89-second measured intervals logged
   capture-queue overflow, zero transport packet drops, mean total CPU use of
   77.17% and 75.67%, and no throttle flags. The external fan was on. Adding
   threads did not remove this bottleneck; full-sensor encoding is unqualified.
9. The actual calibration board is DFVision Q18-400-20: 18×18 squares at 20 mm,
   giving 17×17 internal corners. The first B collection yielded 91 complete
   detections, including repeated stationary frames. Coverage spans different
   image positions and rolls, but apparent linear board size varies only 1.33×.
   Additional distance poses are being collected before the independent A set.
   Detection and fit residuals alone do not establish held-out accuracy or rig
   alignment. Moving the entire rigid rocket with the board fixed is valid.
10. A's completed collection spans 345.57 seconds and contains 9,877 encoded
    frames. Sampling one frame every two seconds produced 173 attempts and 81
    complete-board candidates. These candidate counts are not the video frame
    count. Separately, capture metadata accounts for eight startup errors and
    477 capture-queue overflows during this moving-scene run.
11. Preliminary lens fits retained 27 of 40 selected A views and 43 of 53
    selected B views, with training RMS errors of 0.133 and 0.189 pixels. The
    earlier B model, before incorporating the extra distance session, was tested
    with fixed lens parameters on all 41 complete boards from that new session:
    RMS 0.227 pixels and 95th percentile 0.315 pixels. One difficult view has
    1.13-pixel RMS and remains flagged. Initializing these poses from distorted
    pixels as though they were pinhole coordinates produced a wrong solution;
    inverse Mei bearings and a local virtual perspective view corrected it
    without removing frames. The original failed diagnostic is preserved.
    The newer combined B fit has no independent validation yet, since it now
    uses those distance images for fitting. Both outputs are lens-only; relative
    camera alignment and seam coverage remain unmeasured.
12. An optional CPU-frame copy was tested before encoding, between two direct
    DMA-input controls. Each run lasted 90 seconds, with the first ten excluded
    from comparison. Direct encoded rates were A/B 28.95/29.82 fps, copy rates
    were 24.85/25.62, and repeated direct rates were 28.67/29.59. Copying cost
    about 10.6–10.8 ms per frame: encoder send became faster, but copy plus send
    took about 39–40 ms and delivered fewer frames. All runs had zero transport
    packet drops and no throttle flags. Copy mode was not adopted. These short
    tests do not establish sustained qualification or isolate mapping cache
    attributes as the cause of the bottleneck.

13. Importing cached DMA-heap buffers removed most of the measured software
    encoding bottleneck. In a 90-second cached-buffer run between two allocator
    controls, both cameras encoded 29.995 fps after the first ten seconds, with
    no steady-state queue drops, mean total CPU use of 60.78%, and no throttle
    flags. Mean input-plus-send time was 31.4% lower than the bracketing controls.
    These are live-scene trials, not identical-frame codec comparisons. A later
    180-second ultrafast run averaged 61.63% CPU and 29.988/29.982 encoded fps,
    but logged two A and three B queue overflows. Superfast and veryfast missed
    30 fps substantially. Ultrafast remains the bench choice; the longer run
    prevents claiming zero-drop sustained qualification. Reproducible figures
    and the follow-up evidence are in `output/portfolio/encoder-optimization-001`.
14. The live panorama now uses the measured lens models with operator-supplied
    nominal 180-degree opposed alignment and approximately 0.1524 m baseline.
    Rig rotation remains unmeasured; infinity projection does not use that
    translation or remove near-field parallax. Independent CPU/GPU projection
    comparisons found no orientation error. The remaining near-object seam
    shifts are consistent with the separated viewpoints. Predicted missing
    polar coverage is conditional on the preliminary models, not a measured
    physical field-of-view limit.
15. Sequential ColorChecker Classic observations under the operator's nominal
    5600 K lamp produced a neutral-target display preview. Three unclipped
    middle-gray patches across three frames per camera give RGB gains
    A `[1.10714, 1, 0.93373]`, B `[1.13433, 1, 0.93789]`. Two further frames per
    camera improve too. Fit mean absolute R–G/B–G differences fall from
    11.78 to 3.78 for A and 12.78 to 5.37 for B, in decoded values out of 255.
    These are same-hold neutrality checks, not absolute colour validation.
    Bright patches are clipped; a full colour matrix or A/B exposure match
    would not be justified. Source frames, controls, patch coordinates and
    checks are retained under `output/colour-target-001`. Camera WB and CCM
    remain variable, so this lighting-specific display preview may need
    remeasurement after illumination changes. Original archives are unchanged.
    The selected live preview applies a common scale of 0.881579 to all six
    gains. This preserves corrected chromaticity and relative A/B display level
    while keeping every multiplier at or below one, avoiding new highlight
    clipping. It lowers encoded RGB levels by 11.84%; this is display headroom,
    not a measured exposure adjustment. The complete deployed bundle is
    `output/nominal-panorama-neutral-001/calibration.json`.

16. The operator found B too yellow, particularly on the ceiling. A later chart
    hold in recorded camera B required more blue under the current illumination,
    reversing the earlier lamp-lit blue adjustment. The full fresh neutral fit
    made bright whites pink and added clipping, so the selected preview blends
    49% of that correction with the shared neutral headroom baseline. Effective
    B gains are `[0.999390, 0.881579, 0.928099]`; A remains unchanged. No gain
    exceeds one. Two unclipped patches on the same ceiling panel reduced A/B
    distance in `(R/G, B/G)` from 0.0902 to 0.0199 and 0.0970 to 0.0098. This
    checks one panel under nominal geometry, not absolute colour or every seam.
    The selected bundle is `output/nominal-panorama-neutral-002/calibration.json`;
    fresh chart evidence and ceiling comparisons are in `output/colour-target-002`.
    Both live feeds and the original-colour toggle were verified in the browser.
    A/B strength sliders allow further display adjustment without restarting.

17. A fresh chart hold exposed a tradeoff: its neutral-target fit worsened the
    ceiling match. A smaller A-only display trim reduced the two sampled ceiling
    differences from 0.0352/0.0450 to 0.0235/0.0325, while chart neutrality became
    slightly worse. B stayed unchanged. This visual compromise and rejected fit
    are retained in `output/colour-target-003`; the selected bundle is
    `output/nominal-panorama-neutral-003/calibration.json`.

18. The white-table complaint exposed two issues. Default PyAV RGB extraction
    used BT.601 coefficients despite native BT.709 tags, biasing the colour
    measurements in entries 15–17. Explicit BT.709 conversion and rounding now
    match sampled Chrome pixels; synthetic YUV tests check the matrix and range.
    Original measurements remain archived, but should not guide new fits.
    A table-derived display trim uses gains `[0.972463, 0.881579, 0.924794]`, with
    B unchanged. Across four table regions in three same-hold frames, mean
    `(|R/G−1| + |B/G−1|)/2` falls from 5.40% to 0.85%; bright chart patches
    improve from 11.54% to 6.04%. Two sampled ceiling regions disagree more
    (A/B chromaticity distance about 0.016 → 0.088), so this is a table-prioritized
    preview, not full colour calibration. Evidence is in `output/colour-target-004`
    and `output/colour-conversion-review-001`; the live bundle is
    `output/nominal-panorama-neutral-004/calibration.json`.

19. The brown strip came from camera B. At one automatic-capture sample, A's
    exposure × analogue gain was 1.64 times B's, with different WB and CCM.
    Shared manual controls substantially reduced the visible difference. Both
    cameras report 9980 µs, analogue gain 1.412538, digital gain 1.000629,
    WB `[1.644302, 2.357311]` and identical CCMs. A separate tuning copy disables
    histogram contrast (`rpi.contrast.ce_enable: 0`); the installed vendor file
    is unchanged. Against shared controls with stock contrast, this reduced
    same-pose six-region RGB mismatch from 6.36 to 5.38 codes out of 255.
    The operator accepted this live appearance and deferred the residual seam.
    Earlier automatic/manual images have different rig poses, so they do not
    support a direct numerical before/after claim. Settings, hashes, restart
    instructions and evidence are in `output/colour-seam-005/selected-setup.md`;
    these manual values suit this bench lighting, not a qualified flight exposure
    policy. Capture tests pass on the CM5. Look-around now starts/resets at 110°.

## Evidence and remaining measurements

Local evidence includes `output/provisioning/flash-evidence.json`,
`working-platform-inventory.log`, `latency-before.json`, `latency-after.json`,
`output/camera-bringup-002/`, and `output/sessions/dual-30fps-001/`.
Active focus and full-sensor sessions have distinct native session directories.
A ground transport tap spanning capture restarts contains discontinuous session
timelines and must not be analysed as one uninterrupted capture.

The fan was introduced during interactive testing, so subsequent comparisons
must record that change. Formal preset/resolution comparisons, one-hour
qualification, glass-to-glass latency, independent colour validation, measured
rig alignment, held-out edge/seam lens validation, and electrically/optically
measured exposure synchronization remain outstanding. Current cameras are free
running.

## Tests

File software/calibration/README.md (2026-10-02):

# Lens calibration and the initial panorama

## Saved bench setup

[October 2 configuration](bench-2026-10-02/) preserves the accepted live view:
full 2064×1552 capture, Camera A physically rolled 180°, refined lens models,
separate A/B colour gains and fixed ISP contrast. Both colour strengths are 100%.
The viewer uses narrow feathering with a 48-pixel crop-edge fade.

On the CM5, set `udp_destination` in `capture.json` to the ground computer, then
run from the repository root:

```sh
LIBCAMERA_RPI_TUNING_FILE="$PWD/software/calibration/bench-2026-10-02/fr_imx900-fixed-contrast.json" \
  build/flight/pv-capture --config software/calibration/bench-2026-10-02/capture.json
```

On the ground computer:

```sh
pv view udp://0.0.0.0:1234 --no-browser \
  --calibration software/calibration/bench-2026-10-02/calibration.json
```

Open `http://localhost:8768/`. Recording is off; each capture run gets a new session
directory. Exposure and colour suit the current indoor lighting. Lens checks use
held-out images; precise rig alignment and flight-lighting calibration remain
unfinished. Source images and fitting records stay in the local `build/` archive.

## Calibration workflow

The bench has measured Mei lens fits and a nominal opposed-camera panorama;
edge/seam accuracy and measured rig alignment remain incomplete. See the
[bench evidence](../bench-notes/2026-09-25.md) for results. This guide covers
collection, independent lens fitting and the initial preview; detailed paired
alignment is in [rig-alignment.md](rig-alignment.md).

## Board and collection

The DFVision **Q18-400-20** has 18×18 squares at nominal 20 mm pitch: a 360 mm
pattern on a 400 mm board, giving **17×17 = 289 inner corners**. Confirm the label
and physical pitch. Use [the board preset](boards/dfvision-q18-400-20.json) as the
dataset's `board` object; it takes square counts, while OpenCV takes inner-corner
counts. No ArUco dimensions apply. Datasets without `board.type` retain ChArUco
behavior. [Manufacturer specification](https://www.dfoptic.com/in-stock-standards-product/152.html).

1. Finish focus, then preserve focus/aperture, mounts and camera identity. Record
   settings; changing focus invalidates those intrinsic measurements.
2. Collect original **2064×1552** images from transport or native recordings,
   never resized/cropped previews or browser screenshots. Decoded H.264 retains
   compression artifacts even when saved as PNG.
3. Show the complete sharp, unobstructed grid and border. Vary distance, tilt and
   position across centre, edges and both seams; avoid reflections and blur.
   Move either the board or the entire rigid rocket without adjusting its mounts.
   Hold each pose 2–3 seconds for one-second sampling; only one frame per interval
   is tested. Adjacent frames from one hold are not distinct poses.
4. Aim for 20–30 fit poses and 6–10 independent held-out poses per camera. Normally
   the fitter requires eight accepted fit views and three held-out views. Do not
   split near-identical holds across fitting/validation; counts do not prove coverage.
5. Edge poses must still contain all 289 corners. The SB detector uses exhaustive,
   subpixel refinement and has no partial-board inference or persistent physical
   corner IDs. Preserve missed detections and coverage gaps. A central fit does
   not validate >90° rays or seams.
   [OpenCV detector documentation](https://docs.opencv.org/4.x/d9/d0c/group__calib3d.html).

## Extract and curate

From the repository root, use a local copy of `session.json`, `frames.jsonl`,
`segments.jsonl` and finalized A/B MKVs:

```sh
software/.venv/bin/python software/tools/calibration_frames.py \
  --session output/sessions/calibration-fit-001 \
  --board software/calibration/boards/dfvision-q18-400-20.json \
  --output output/calibration/fit-candidates-001 \
  --interval-seconds 1 --split fit --require-board
```

Use another recording/output with `--split validation` for held-out poses.
`--camera A` or `--camera B` avoids searching the opposite camera when collecting
one lens; default is both. `--require-board` keeps complete detections; omit it
for unchecked candidates. Set useful `--region` labels; default is `unlabelled`,
and labels beginning `seam` are reported separately. Curate diversity before fitting.

Output includes original-orientation PNGs, `dataset.json` and
`collection-report.json`. Records retain segment/PNG hashes, container PTS/timebase,
original capture metadata/common PTS, physical IDs and geometry. Matching allows
only MKV rounding uncertainty; ambiguous metadata and unknown/cropped geometry
are rejected. Missing indexed, unfinalized and unindexed segments are reported,
so a partial copy is not called complete. Existing outputs are refused. The
collector neither accesses the Pi nor fits lenses/alignment.

Native PNG extraction requires limited-range BT.709 YUV420 tags and records the
explicit matrix/range conversion. These pixels retain the BT.709 transfer curve;
they are not linear-light or colour-managed sRGB measurements.

Each camera's image list needs paths relative to its dataset, explicit
`fit`/`validation` splits and region labels. Preserve `physical_cameras`,
`image_orientation`, per-image `device_id` and `capture_metadata` when merging
collections. Use actual capture `flip_x`/`flip_y`, not browser rotation; the
fitter reverses them before detection so intrinsics describe canonical unflipped
full-sensor pixels. Keep common timestamps/offsets and actual sensor crop.
Padding a cropped image back to full size is invalid.

For manual originals, each record instead needs `source_provenance`:
`kind:"manual_full_sensor"`, `camera_id`, `device_id`, `sensor_crop`, `flip_x`,
`flip_y` and a nonempty acquisition `note`. It must match the dataset's physical
camera description and cannot override contradictory extractor metadata.

## Fit and check lenses

Fit a lens independently; omit `--camera` to process every nonempty camera list:

```sh
software/.venv/bin/pv calibrate --intrinsics-only --camera B \
  --dataset output/calibration/dataset.json --output output/calibration/B-fit-01
```

`intrinsics.json` has `scope:"intrinsics_only"`, `rig_alignment_status:"unmeasured"`
and no camera-to-rig rotation; it cannot enable a panorama. IDs, dimensions,
crop/orientation and supplied image hashes are checked before fitting.

For a collecting-stage diagnostic, explicitly add `--allow-unvalidated`.
Eight accepted fit views are still required. Insufficient held-out evidence gives
`unvalidated_intrinsics`, null threshold results and no measured angular limit.
Training RMS is not validation. Once new-session observations enter a refit,
their earlier test against a frozen model no longer validates the new model.

Read `observations.json` for rejected/retained views and residuals; inspect
held-out RMS/p95, region/seam errors and coverage in the output bundle. Targets
are ≤1 px RMS and ≤2 px p95. Central accuracy does not qualify seams;
`max_theta_deg` is the largest observed held-out ray, not proof that all enclosed
rays were tested.

## Initial nominal opposed-camera preview

An initial demo can combine real lens fits with approximate operator geometry
before a measured rig solve. A is the reference; B rotates 180° about rig Y,
assuming parallel canonical +Y axes (zero relative roll). The example records an
approximate six-inch baseline; infinity projection **does not correct parallax**.

```sh
software/.venv/bin/python software/tools/nominal_rig_preview.py \
  --intrinsics-a PATH/A-intrinsics.json --intrinsics-b PATH/B-intrinsics.json \
  --dataset-b PATH/B-source-dataset.json --output output/nominal-preview \
  --baseline-m 0.1524 --geometry-source-date 2026-09-25 \
  --opposed --common-roll-assumed
```

Use the actual source date/separation. Normal intrinsics bind their source dataset
and hash; flat diagnostics need explicit datasets (repeat `--dataset-b` for
combined fits). The generator verifies physical IDs and full-sensor FlipY geometry,
refuses existing output, and writes `calibration.json` with
`rig_alignment_status:nominal_operator_geometry`, `qualified:false`. Lens validation
states and missing angular limits remain unchanged; alignment and seam coverage
are still unmeasured.

## Measured alignment is separate

A symmetric checkerboard's detector-local corner order can rotate between views.
**Do not equate A/B corner indices.** Paired alignment needs a marked physical
origin/axes, verified correspondence, the same printed face/full grid in both
cameras, original timestamps and stationary holds. Nearest timestamps do not
prove exposure synchronization. Follow the [paired alignment workflow](rig-alignment.md);
if full-board overlap is unavailable, record that limit and design another
measurement. Camera separation still causes depth-dependent parallax.

With a separately measured rig JSON specifying sensor size, crop/output/flips
and `R_camera_from_rig`, fit the combined bundle:

```sh
software/.venv/bin/pv calibrate --dataset output/calibration/dataset.json \
  --rig output/calibration/rig.json --output output/calibration/fit-01
```

Unrelated A/B board poses do not determine rig alignment; never label nominal
rotations as measured to enable a viewer.

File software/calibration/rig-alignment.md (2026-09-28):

# Measured alignment of the two mounted cameras

`pigeonvision.rig_calibration` is an offline solver for a shared rigid transform
between two cameras with **frozen Mei lens parameters**. It writes a separate
evidence report. It does not modify the live viewer or produce a panorama-ready
`calibration.json`. No real paired alignment observations have been collected yet.

## Operator collection

Keep both cameras in their final rigid mount and preserve lens focus. Start by
finding **one complete board visible simultaneously in both original images**.
Place the board to a side of the rocket with its printed face toward both lenses.
Move it farther if needed to fit in the shared field, while keeping individual
squares large and sharp enough to detect. Sensor cropping, lens edge quality and
body occlusion can make the complete grid unavailable in the nominal overlap.
A supplier FOV prediction does not establish usable installed overlap.

Both cameras must see the same printed face and physical corners. Moving the
assembled rocket while keeping the board stationary is valid; hold both still
for each chosen pair. Nearest timestamps alone do not establish synchronization.
Keep original full-sensor images and metadata, not rotated viewer screenshots.

For the symmetric DFVision board, mark **O**, **X** and **Y** on the outer margin
without covering the checker pattern. Define O beside one chosen physical inner
corner. X identifies the far end of that corner's row; Y identifies the far end
of its column. On the 17 × 17 inner grid:

- O is physical ID 0, at `(0, 0, 0)` metres.
- X is physical ID 16, at `(0.320, 0, 0)` metres.
- Y is physical ID 272, at `(0, 0.320, 0)` metres.
- Every corner ID is `row * 17 + column`; coordinates are
  `(column * 0.020, row * 0.020, 0)` metres.

The meaning is physical: an image's top-left detector corner need not be O.
For **every pair and each camera**, inspect the marked board, reorder detected
corners to these physical IDs, and independently click the three corresponding
inner corners. Store those clicks as `anchor_pixels`. The solver checks each
click against its declared ID within 3 pixels. An incorrectly rotated ID grid
that contradicts the clicks is rejected. Consistently false operator labels
cannot be proven correct by a numerical fit; the confirmation must be real.

Coordinates are canonical, unflipped full-sensor pixel centres. Undo the capture
session's `flip_x`/`flip_y` for annotation only; retain the original image bytes
and their hash. Ignore the browser's independent viewing rotation.

Collect at least **eight distinct fitting pairs** with different board positions,
distances and tilts. Reserve **three distinct held-out pairs per declared seam**.
For the two seam directions this means at least six held-out pairs. Assign one
`pose_group` per physical stationary hold and choose one pair from it. Do not
split frames from one hold between fitting and validation. Identical or nearly
identical grids are rejected even if their group names differ.

If a complete shared grid is not visible, stop this workflow. A separately
designed ID-bearing partial target or surveyed multi-target arrangement is needed.
Alternating unrelated board views does not establish the mounted relative pose.

## Input contract

Call the module independently from the existing CLI:

```sh
software/.venv/bin/python -m pigeonvision.rig_calibration \
  --dataset output/alignment/observations.json --output output/alignment/fit-01
```

Or call `calibrate_rig(dataset_path: Path, output: Path)`. The output directory
must not already exist. Paths inside the dataset are relative to its JSON file.

The top-level JSON fields are:

| Field | Required meaning |
| --- | --- |
| `schema_version` | `1` |
| `kind` | `"rig_alignment_observations"` |
| `evidence_kind` | `"camera_capture"` for actual observations; `"synthetic_fixture"` for tests |
| `coordinate_convention` | `"unflipped_full_sensor_pixel_centres"` |
| `assembly_unchanged_confirmed` | Explicit `true` after checking mount and focus |
| `board` | Checkerboard type, square counts and measured square pitch, as in the existing board preset |
| `physical_cameras`, `image_orientation` | The full-sensor physical descriptions and capture flips from the collector |
| `intrinsics` | `{"A": "A-intrinsics.json", "B": "B-intrinsics.json"}`; each file identifies that physical device and image size |
| `seams` | Distinct labels such as `["seam-left", "seam-right"]` |
| `max_pair_skew_us` | Optional, defaults to 20000; absolute original sensor-timestamp difference |
| `pairs` | Actual paired observations described below |

Every pair has nonempty `pair_id`, `pose_group`, and `seam`, an explicit `split`
(`"fit"` or `"validation"`), and `stationary_hold_confirmed: true`. Its
`correspondence` object requires `operator_confirmed: true`,
`same_printed_face: true`, and a nonempty `note` documenting the physical marks.

`frames.A` and `frames.B` each retain the collector's `path`, `sha256`, `device_id`
and `capture_metadata`. Add these fields without rewriting original metadata:

| Frame field | Meaning |
| --- | --- |
| `session_id` | Original native session ID, identical within the A/B pair |
| `clock_domain` | `"CLOCK_BOOTTIME"` |
| `clock_origin_ns` | The original common session origin, identical for A/B |
| `image_orientation` | Explicit original capture `flip_x`/`flip_y`, matching the physical description |
| `corner_ids` | Every physical inner-corner ID exactly once; array order may differ between cameras |
| `image_points` | Corresponding canonical `[u,v]` points, in the same order as this frame's `corner_ids` |
| `anchor_pixels` | `{"O": [u,v], "X": [u,v], "Y": [u,v]}` from independent operator identification |

Native `capture_metadata` must identify the logical camera, encoded frame status,
original sequence, `sensor_timestamp_ns`, `pts_us`, and actual full `sensor_crop`.
The fitter verifies `pts_us == (sensor_timestamp_ns - clock_origin_ns) // 1000`.
It checks image hashes/dimensions, physical IDs, crop, orientation, shared origin,
timing tolerance and the anchor correspondences. It does not independently rebase
the streams or silently equate matching detector-array positions.

## Solve and evidence

The board pose initializer uses inverse Mei bearings and a local virtual forward
view, including boards beyond the camera's pinhole forward hemisphere. This is
only a pose calculation. No rig alignment is assumed by the initializer.

For each fitting pair, independent initial board poses provide:

```text
R_B_from_A = R_B_from_board @ R_A_from_board.T
t_B_from_A = t_B_from_board - R_B_from_A @ t_A_from_board
X_B = R_B_from_A @ X_A + t_B_from_A
```

The joint solver refines one shared rotation and **translation in metres** plus
one board pose per pair. Both cameras' K, D and xi remain fixed. Translation is
necessary for the finite-distance board, even if a future infinity panorama uses
only rotation. B's optical centre in A coordinates is `-R_B_from_A.T @ t_B_from_A`.
The reported frame is A's optical frame; alignment to rocket-body axes is separate.

For a held-out pair, the fitted relative transform and both lens models remain
frozen. Only a single board pose is fitted jointly to A and B. The report includes
per-camera training and held-out residuals, per-seam held-out residuals, pair-level
errors, rejected inputs, source hashes, skew and local numerical observability.
Targets are ≤1 pixel RMS and ≤2 pixels p95 for every evaluated camera/pair.
This holdout is **alignment-only, conditional on the supplied lens models**.
Overlap with their original training images or physical holds is not audited;
the report explicitly marks that unknown. It does not claim independent validation
of the entire lens-plus-rig stack. Reserve additional observations independent of
both lens fitting and alignment fitting when assessing the full stack.

`rig-alignment.json` can contain a `candidate_transform` even when checks fail.
Its `status` is authoritative. A measured status requires enough distinct fit and
held-out pairs, valid Mei projections, residual targets and local full-rank geometry.
Synthetic datasets always remain `synthetic_test_only`, never real measurements.
Insufficient observations or failed checks leave `rig_alignment_status: "unmeasured"`.
Source intrinsic-validation status is retained; this report only checks observed
seam/board rays, not the lens's entire FOV. A measured result still has
`panorama_ready: false` until separately reviewed and integrated.

No translation estimate can remove arbitrary near-scene parallax from two
spatially separated cameras using one infinity projection.

OpenCV's omnidirectional stereo workflow likewise requires shared observations
of the same pattern and reports the relative rotation and translation.
[Official OpenCV tutorial](https://docs.opencv.org/4.9.0/dd/d12/tutorial_omnidir_calib_main.html).

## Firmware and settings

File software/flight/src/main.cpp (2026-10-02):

#include "pv/camera.hpp"
#include "pv/config.hpp"
#include "pv/log.hpp"
#include "pv/outputs.hpp"
#include "pv/session.hpp"
#include "pv/supervisor.hpp"
#include "pv/sensors.hpp"
#include "pv/flight_uart.hpp"
#include "pv/telemetry_batcher.hpp"
#include <sys/utsname.h>
#include <csignal>
#include <fstream>
#include <iostream>
#include <thread>
extern "C" {
#include <libavutil/avutil.h>
}

namespace {
volatile std::sig_atomic_t interrupted = 0;
void signal_handler(int signal) {
  interrupted = signal;
}
std::int64_t monotonic_ns() {
  timespec ts{};
  if (clock_gettime(CLOCK_MONOTONIC, &ts))
    throw std::runtime_error("CLOCK_MONOTONIC unavailable");
  return std::int64_t(ts.tv_sec) * 1000000000 + ts.tv_nsec;
}
void write_status(const std::filesystem::path &path, const pv::Json &record) {
  std::ofstream file(path.string() + ".tmp");
  file << record.dump() << '\n';
  file.close();
  if (!file)
    return;
  std::error_code error;
  std::filesystem::rename(path.string() + ".tmp", path, error);
}
std::string device_model() {
  std::ifstream f("/proc/device-tree/model");
  std::string model;
  std::getline(f, model, '\0');
  return model;
}
} // namespace
int main(int argc, char **argv) {
  try {
    if (argc == 2 && std::string(argv[1]) == "--help") {
      std::cout << "pv-capture --list-cameras\npv-capture --config path.json\npv-capture --status "
                   "[path.json]\n";
      return 0;
    }
    if ((argc == 2 || argc == 3) && std::string(argv[1]) == "--status") {
      std::ifstream status(argc == 3 ? argv[2] : "/run/pv-capture-status.json");
      if (!status)
        return 1;
      std::cout << status.rdbuf();
      return 0;
    }
    const bool list = argc == 2 && std::string(argv[1]) == "--list-cameras";
    if (!list && !(argc == 3 && std::string(argv[1]) == "--config")) {
      std::cerr << "usage: pv-capture --list-cameras | --config path.json\n";
      return 2;
    }
    libcamera::CameraManager manager;
    if (list) {
      if (manager.start() < 0)
        throw std::runtime_error("cannot start CameraManager");
      std::cout << pv::enumerate_cameras(manager).dump(2) << '\n';
      return 0;
    }
    auto config = pv::Config::read(argv[2]);
    pv::CaptureLock capture_lock(config.lock_path);
    pv::Supervisor supervisor;
    supervisor.transition(pv::Lifecycle::initializing);
    const bool camera_manager_ready = manager.start() >= 0;
    supervisor.component("camera_manager", camera_manager_ready ? "ready" : "failed");
    std::error_code existence_error;
    if (std::filesystem::exists(config.session_dir / "session.json", existence_error))
      throw std::runtime_error("session.json already exists; choose a new session directory");
    std::error_code storage_error;
    std::filesystem::create_directories(config.session_dir, storage_error);
    pv::Logs logs(config.session_dir);
    const auto mono_before = monotonic_ns(), origin = pv::boot_ns(), mono_after = monotonic_ns();
    std::unique_ptr<pv::Outputs> outputs;
    std::vector<std::unique_ptr<pv::CameraSession>> cameras;
    std::vector<pv::StreamInfo> streams;
    pv::Json descriptions = pv::Json::array();
    for (const auto &camera : config.cameras) {
      try {
        if (!camera_manager_ready)
          throw std::runtime_error("CameraManager unavailable");
        auto session = std::make_unique<pv::CameraSession>(manager, config, camera, logs, origin);
        descriptions.push_back(session->description());
        if (config.encode)
          streams.push_back(session->stream_info());
        cameras.push_back(std::move(session));
      } catch (const std::exception &e) {
        supervisor.component(camera.id, "failed");
        logs.event("camera", "initialization_failed", camera.id, e.what());
      }
    }
    utsname system{};
    uname(&system);
    pv::Json manifest{{"schema_version", 1},
                      {"session_id", config.session_dir.filename().string()},
                      {"created_utc", pv::utc_now()},
                      {"clock_origin_ns", origin},
                      {"clock_domain", "CLOCK_BOOTTIME"},
                      {"clock_sample",
                       {{"monotonic_before_ns", mono_before},
                        {"boottime_ns", origin},
                        {"monotonic_after_ns", mono_after}}},
                      {"configuration", config.effective()},
                      {"software",
                       {{"capture_version", "0.1.0"},
                        {"libcamera", libcamera::CameraManager::version()},
                        {"ffmpeg", av_version_info()}}},
                      {"hardware",
                       {{"model", device_model()},
                        {"kernel", system.release},
                        {"architecture", system.machine},
                        {"cameras", descriptions}}},
                      {"calibration", nullptr},
                      {"sensor_timestamp_optically_verified", false}};
    manifest["transport"] = {{"pts_offset_us", 1000000},
                             {"mux_delay_us", 500000},
                             {"metadata_pes_clock", "producer_queue_admission"},
                             {"video_pids", {{"A", 256}, {"B", 257}}},
                             {"metadata_pid", 258}};
    {
      std::ofstream file(config.session_dir / "session.json.tmp");
      file << manifest.dump(2) << '\n';
      file.flush();
      if (!file)
        logs.event("storage", "manifest_failed");
    }
    std::filesystem::rename(config.session_dir / "session.json.tmp",
                            config.session_dir / "session.json", storage_error);
    outputs = std::make_unique<pv::Outputs>(config, logs, streams, origin);
    std::signal(SIGINT, signal_handler);
    std::signal(SIGTERM, signal_handler);
    std::signal(SIGPIPE, SIG_IGN);
    bool runtime_failed = cameras.size() != config.cameras.size();
    for (auto &camera : cameras) {
      try {
        camera->start(*outputs);
      } catch (const std::exception &e) {
        runtime_failed = true;
        logs.event("camera", "start_failed", "", e.what());
        camera->stop();
      }
    }
    pv::TelemetryBatcher telemetry;
    auto publish_sample = [&](pv::Json record) {
      const auto now = pv::boot_ns();
      record["pts_us"] = (now - origin) / 1000;
      record["publication_timestamp_ns"] = now;
      record["clock_domain"] = "CLOCK_BOOTTIME";
      record["acquisition_clock_domain"] =
          record.value("host_clock_domain", std::string("CLOCK_BOOTTIME"));
      logs.sensor(record);
      if (record.value("type", std::string()) == "sensor_sample")
        telemetry.add(record);
      else
        outputs->metadata(record);
    };
    pv::SensorWorker sensors(config.original.value("sensors", pv::Json{{"backend", "disabled"}}),
                             publish_sample);
    pv::FlightUartWorker uart(
        config.original.value("flight_uart", pv::Json{{"backend", "disabled"}}), publish_sample);
    sensors.start();
    uart.start();
    supervisor.transition(pv::Lifecycle::running);
    const auto run_start = pv::boot_ns();
    logs.event("session", "started");
    std::cout << pv::Json{{"type", "session"},
                          {"session_dir", config.session_dir.string()},
                          {"camera_count", cameras.size()}}
                     .dump()
              << std::endl;
    pv::Json wire_session{{"schema_version", 1},
                          {"type", "session"},
                          {"session_id", manifest["session_id"]},
                          {"clock_origin_ns", origin},
                          {"clock_domain", "CLOCK_BOOTTIME"},
                          {"cameras", descriptions},
                          {"transport_pts_offset_us", 1000000},
                          {"metadata_pes_clock", "producer_queue_admission"},
                          {"pts_us", (run_start - origin) / 1000}};
    outputs->metadata(wire_session);
    auto next_health = run_start;
    auto next_telemetry = run_start;
    while (!interrupted) {
      const auto now = pv::boot_ns();
      if (now >= next_telemetry) {
        for (auto &batch :
             telemetry.take(manifest["session_id"].get<std::string>(), (now - origin) / 1000))
          outputs->metadata(batch);
        next_telemetry = now + 100000000;
      }
      if (config.duration_seconds && (now - run_start) / 1e9 >= config.duration_seconds)
        break;
      for (auto &camera : cameras) {
        const auto state = camera->stats();
        const auto last = state["last_frame_ns"].get<std::int64_t>();
        if (state["active"].get<bool>() &&
            (camera->failed() || now - (last ? last : run_start) > 2000000000LL)) {
          logs.event("camera", camera->failed() ? "disabled_after_failure" : "stalled",
                     state["camera_id"].get<std::string>());
          camera->stop();
          runtime_failed = true;
        }
        supervisor.component(state["camera_id"].get<std::string>(),
                             camera->failed()                        ? "failed"
                             : camera->stats()["active"].get<bool>() ? "capturing"
                                                                     : "disabled");
      }
      supervisor.component("storage", logs.failed() ? "failed" : "recording");
      if (now >= next_health) {
        auto health = pv::system_health();
        health["cameras"] = pv::Json::array();
        std::size_t healthy = 0;
        for (auto &camera : cameras) {
          auto s = camera->stats();
          if (s["active"].get<bool>() && !camera->failed())
            ++healthy;
          health["cameras"].push_back(std::move(s));
        }
        health["sensors"] = sensors.stats();
        health["flight_uart"] = uart.stats();
        health["phase"] = health["flight_uart"].value("phase", std::string("UNKNOWN"));
        health["phase_stale"] = health["flight_uart"].value("stale", true);
        health["degraded"] = cameras.size() != config.cameras.size() ||
                             healthy != config.cameras.size() || logs.failed();
        health["lifecycle"] = pv::name(supervisor.state());
        health["components"] = supervisor.components();
        health["outputs"] = outputs->stats();
        const auto &transport = health["outputs"]["transport"];
        if (!transport.is_null()) {
          const bool failed = transport.value("failed", false);
          supervisor.component("transport", failed ? "failed" : "transmitting");
          health["degraded"] = health["degraded"].get<bool>() || failed;
        }
        for (const auto &[id, recorder] : health["outputs"]["recorders"].items()) {
          const bool failed = recorder.value("failed", false);
          supervisor.component("recording_" + id, failed ? "failed" : "recording");
          health["degraded"] = health["degraded"].get<bool>() || failed;
        }
        if (health["sensors"]["backend"] != "disabled") {
          for (const auto &[id, sensor] : health["sensors"]["devices"].items()) {
            const auto last_good = sensor.value("last_good_monotonic_us", pv::Json(nullptr));
            const auto status = sensor.value("status", std::string("unavailable"));
            const bool fresh = (status == "fresh" || status == "not_ready") &&
                               last_good.is_number_integer() &&
                               now / 1000 - last_good.get<std::int64_t>() < 1000000;
            supervisor.component(id, fresh ? "receiving" : sensor.value("status", "unavailable"));
            health["degraded"] = health["degraded"].get<bool>() || !fresh;
          }
        }
        if (config.original.value("flight_uart", pv::Json::object()).value("backend", "disabled") !=
            "disabled") {
          const bool stale = health["flight_uart"].value("stale", true);
          supervisor.component("flight_uart", stale ? "stale" : "receiving");
          health["degraded"] = health["degraded"].get<bool>() || stale;
        }
        health["components"] = supervisor.components();
        health["log_records_lost"] = logs.lost();
        health["log_failed"] = logs.failed();
        health["type"] = "health";
        health["session_id"] = manifest["session_id"];
        health["pts_us"] = (now - origin) / 1000;
        health["clock_domain"] = "CLOCK_BOOTTIME";
        health["timestamp_ns"] = now;
        health["schema_version"] = 1;
        wire_session["pts_us"] = (now - origin) / 1000;
        outputs->metadata(
            wire_session); // Late UDP joins recover geometry/timeline at the next GOP.
        outputs->metadata(health);
        logs.health(health);
        std::cout << health.dump() << std::endl;
        write_status(config.status_path, health);
        next_health = now + 1000000000;
      }
      std::this_thread::sleep_for(std::chrono::milliseconds(50));
    }
    supervisor.transition(pv::Lifecycle::stopping);
    sensors.stop();
    uart.stop();
    for (auto &batch :
         telemetry.take(manifest["session_id"].get<std::string>(), (pv::boot_ns() - origin) / 1000))
      outputs->metadata(batch);
    for (auto &camera : cameras) {
      camera->stop();
      if (camera->failed())
        runtime_failed = true;
    }
    outputs->stop();
    auto final_stats = outputs->stats();
    for (const auto &[_, recorder] : final_stats["recorders"].items())
      if (recorder["failed"].get<bool>())
        runtime_failed = true;
    if (!final_stats["transport"].is_null() && final_stats["transport"]["failed"].get<bool>())
      runtime_failed = true;
    logs.health({{"type", "session_end"},
                 {"signal", int(interrupted)},
                 {"outputs", final_stats},
                 {"failed", runtime_failed}});
    logs.finish();
    runtime_failed = runtime_failed || logs.failed() || logs.lost();
    supervisor.transition(pv::Lifecycle::stopped);
    {
      pv::Json stopped{{"type", "health"},
                       {"lifecycle", "stopped"},
                       {"timestamp_ns", pv::boot_ns()},
                       {"outputs", final_stats},
                       {"failed", runtime_failed},
                       {"session_id", manifest["session_id"]}};
      write_status(config.status_path, stopped);
    }
    if (config.spi && final_stats.contains("transport") && !final_stats["transport"].is_null() &&
        final_stats["transport"].contains("spi") &&
        final_stats["transport"]["spi"].value("transfer_uncertain", false))
      return 78;
    return runtime_failed || logs.failed() || logs.lost() ? 1 : 0;
  } catch (const std::exception &e) {
    std::cerr << "pv-capture: " << e.what() << '\n';
    return 1;
  }
}

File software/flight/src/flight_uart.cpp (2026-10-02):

#include "pv/flight_uart.hpp"

#include <fcntl.h>
#include <poll.h>
#include <termios.h>
#include <unistd.h>

#include <algorithm>
#include <atomic>
#include <charconv>
#include <chrono>
#include <cstdio>
#include <mutex>
#include <stdexcept>
#include <thread>
#include <vector>

#include "pv/acquisition_clock.hpp"
namespace pv {
namespace {
std::int64_t now_us() {
  return acquisition_us();
}
bool newer(std::uint32_t a, std::uint32_t b) {
  auto delta = a - b;
  return delta && delta < 0x80000000U;
}
bool number(std::string_view s, std::uint32_t &n) {
  if (s.empty())
    return false;
  auto [p, e] = std::from_chars(s.data(), s.data() + s.size(), n);
  return e == std::errc{} && p == s.data() + s.size();
}
bool allowed(std::string_view x, std::initializer_list<std::string_view> list) {
  return std::find(list.begin(), list.end(), x) != list.end();
}
} // namespace
std::uint16_t flight_crc16(std::string_view bytes) {
  std::uint16_t crc = 0xffff;
  for (unsigned char c : bytes) {
    crc ^= std::uint16_t(c) << 8;
    for (int i = 0; i < 8; ++i)
      crc = std::uint16_t((crc << 1) ^ ((crc & 0x8000) ? 0x1021 : 0));
  }
  return crc;
}
void FlightUartParser::feed(std::string_view bytes, std::int64_t time) {
  for (char c : bytes) {
    if (c == '\n') {
      if (!dropping_)
        line(time);
      buffer_.clear();
      dropping_ = false;
    } else if (!dropping_) {
      if (buffer_.size() >= 95) {
        ++malformed_;
        buffer_.clear();
        dropping_ = true;
      } else
        buffer_ += c;
    }
  }
}
void FlightUartParser::line(std::int64_t time) {
  auto star = buffer_.find('*');
  if (star == std::string::npos || star + 5 != buffer_.size()) {
    ++malformed_;
    return;
  }
  unsigned crc = 0;
  auto [p, e] =
      std::from_chars(buffer_.data() + star + 1, buffer_.data() + buffer_.size(), crc, 16);
  if (e != std::errc{} || p != buffer_.data() + buffer_.size()) {
    ++malformed_;
    return;
  }
  std::string_view body(buffer_.data(), star);
  if (crc != flight_crc16(body)) {
    ++bad_crc_;
    return;
  }
  std::vector<std::string_view> fields;
  std::size_t start = 0;
  for (std::size_t i = 0; i <= body.size(); ++i)
    if (i == body.size() || body[i] == ',') {
      fields.push_back(body.substr(start, i - start));
      start = i + 1;
    }
  std::uint32_t seq, uptime, event_seq;
  if (fields.size() != 6 || fields[0] != "PV1" || !number(fields[1], seq) ||
      !number(fields[2], uptime) || !number(fields[4], event_seq) ||
      !allowed(fields[3], {"UNKNOWN", "PAD", "ASCENT", "DESCENT", "LANDED"}) ||
      !allowed(fields[5], {"NONE", "LAUNCH", "APOGEE", "DEPLOYMENT", "LANDED"})) {
    ++malformed_;
    return;
  }
  bool forward =
      !have_ || (newer(seq, sequence_) && (uptime == uptime_ || newer(uptime, uptime_)) &&
                 (event_seq == event_sequence_ || newer(event_seq, event_sequence_)));
  bool reacquired = false;
  if (have_ && !forward && time - receive_us_ >= 3000000) {
    // No boot identifier exists on the wire. Two progressing valid frames after
    // staleness infer an epoch; they do not prove that the FC physically rebooted.
    if (candidate_ && time - candidate_receive_us_ < 3000000 && newer(seq, candidate_seq_) &&
        newer(uptime, candidate_uptime_) &&
        (event_seq == candidate_event_seq_ || newer(event_seq, candidate_event_seq_)) &&
        (event_seq != candidate_event_seq_ || fields[5] == candidate_event_)) {
      ++inferred_epoch_;
      reacquired = true;
      candidate_ = false;
    } else {
      candidate_ = true;
      candidate_seq_ = seq;
      candidate_uptime_ = uptime;
      candidate_event_seq_ = event_seq;
      candidate_event_ = fields[5];
      candidate_receive_us_ = time;
      ++out_of_order_;
      return;
    }
  }
  if (have_ && !reacquired) {
    if (seq == sequence_) {
      ++duplicate_;
      return;
    }
    if (!forward) {
      ++out_of_order_;
      return;
    }
    if (event_seq == event_sequence_ && fields[5] != event_) {
      ++malformed_;
      return;
    }
  }
  candidate_ = false;
  bool changed_event =
      (!have_ || reacquired || event_seq != event_sequence_) && fields[5] != "NONE";
  have_ = true;
  sequence_ = seq;
  uptime_ = uptime;
  event_sequence_ = event_seq;
  phase_ = fields[3];
  event_ = fields[5];
  receive_us_ = time;
  ++accepted_;
  if (changed_event) {
    auto record = snapshot(time);
    record["type"] = "flight_event";
    if (events_.size() == 16) {
      events_.erase(events_.begin());
      ++dropped_events_;
    }
    events_.push_back(std::move(record));
  }
}
nlohmann::json FlightUartParser::snapshot(std::int64_t time) const {
  bool stale = !have_ || time - receive_us_ >= 3000000;
  return {{"type", "flight_status"},
          {"valid", have_ && !stale},
          {"stale", stale},
          {"phase", stale ? "UNKNOWN" : phase_},
          {"event", event_},
          {"inferred_epoch", inferred_epoch_},
          {"epoch_reacquisition_pending", candidate_},
          {"seq", have_ ? nlohmann::json(sequence_) : nlohmann::json(nullptr)},
          {"event_seq", have_ ? nlohmann::json(event_sequence_) : nlohmann::json(nullptr)},
          {"fc_uptime_ms", have_ ? nlohmann::json(uptime_) : nlohmann::json(nullptr)},
          {"receive_monotonic_us", have_ ? nlohmann::json(receive_us_) : nlohmann::json(nullptr)},
          {"monotonic_us", time},
          {"host_clock_domain", acquisition_clock_domain()},
          {"counters",
           {{"accepted", accepted_},
            {"bad_crc", bad_crc_},
            {"malformed", malformed_},
            {"duplicate", duplicate_},
            {"out_of_order", out_of_order_},
            {"dropped_events", dropped_events_}}}};
}
std::vector<nlohmann::json> FlightUartParser::take_events() {
  auto result = std::move(events_);
  events_.clear();
  return result;
}
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

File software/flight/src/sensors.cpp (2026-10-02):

#include "pv/sensors.hpp"

#include <fcntl.h>
#include <unistd.h>

#include <atomic>
#include <chrono>
#include <cmath>
#include <mutex>
#include <stdexcept>
#include <thread>
#include <vector>

#include "../vendor/bmi08x/bmi08.h"
#include "../vendor/bmp5/bmp5.h"
#include "pv/acquisition_clock.hpp"
#ifdef __linux__
#include <linux/i2c-dev.h>
#include <linux/i2c.h>
#include <sys/ioctl.h>
#endif
namespace pv {
namespace sensor_conversion {
std::array<double, 3> acceleration(const std::array<std::int16_t, 3> &raw) {
  std::array<double, 3> v{};
  for (int i = 0; i < 3; ++i)
    v[i] = raw[i] * (24.0 * 9.80665 / 32768.0);
  return v;
}
std::array<double, 3> angular_rate(const std::array<std::int16_t, 3> &raw) {
  std::array<double, 3> v{};
  for (int i = 0; i < 3; ++i)
    v[i] = raw[i] * (2000.0 * 3.141592653589793 / 180.0 / 32768.0);
  return v;
}
nlohmann::json ina226(std::int16_t shunt, std::uint16_t bus, std::int16_t current,
                      std::uint16_t power) {
  return {{"shunt_voltage_v", shunt * 0.0000025},
          {"bus_voltage_v", bus * 0.00125},
          {"current_a", current * 0.001},
          {"power_w", current < 0 ? bus * 0.00125 * current * 0.001 : power * 0.025},
          {"power_basis", current < 0 ? "bus_times_current" : "power_register"},
          {"saturated", shunt == INT16_MIN || shunt == INT16_MAX || current == INT16_MIN ||
                            current == INT16_MAX}};
}
} // namespace sensor_conversion
namespace {
using Json = nlohmann::json;
using Clock = std::chrono::steady_clock;
std::int64_t now_us() {
  return acquisition_us();
}
struct Bus {
  std::string path;
  int address = -1, fd = -1;
  ~Bus() { close_bus(); }
  void close_bus() {
    if (fd >= 0)
      close(fd);
    fd = -1;
  }
  bool open_bus() {
#ifdef __linux__
    if (path.empty() || address < 0x08 || address > 0x77)
      return false;
    fd = open(path.c_str(), O_RDWR | O_CLOEXEC);
    if (fd < 0)
      return false;
    // Kernel adapters may reject these controls; refusal is a fault rather than an unbounded retry
    // loop.
    if (ioctl(fd, I2C_TIMEOUT, 10) < 0 || ioctl(fd, I2C_RETRIES, 1) < 0) {
      close_bus();
      return false;
    }
    return true;
#else
    return false;
#endif
  }
  bool read(std::uint8_t reg, std::uint8_t *data, std::uint32_t len) {
#ifdef __linux__
    if (fd < 0 || len > 256)
      return false;
    i2c_msg msgs[2]{{static_cast<__u16>(address), 0, 1, &reg},
                    {static_cast<__u16>(address), I2C_M_RD, static_cast<__u16>(len), data}};
    i2c_rdwr_ioctl_data request{msgs, 2};
    return ioctl(fd, I2C_RDWR, &request) == 2;
#else
    (void)reg;
    (void)data;
    (void)len;
    return false;
#endif
  }
  bool write(std::uint8_t reg, const std::uint8_t *data, std::uint32_t len) {
#ifdef __linux__
    if (fd < 0 || len > 255)
      return false;
    std::vector<std::uint8_t> bytes{reg};
    bytes.insert(bytes.end(), data, data + len);
    i2c_msg message{static_cast<__u16>(address), 0, static_cast<__u16>(bytes.size()), bytes.data()};
    i2c_rdwr_ioctl_data request{&message, 1};
    return ioctl(fd, I2C_RDWR, &request) == 1;
#else
    (void)reg;
    (void)data;
    (void)len;
    return false;
#endif
  }
  std::uint8_t byte(std::uint8_t reg) {
    std::uint8_t x;
    if (!read(reg, &x, 1))
      throw std::runtime_error("read failed");
    return x;
  }
  void byte(std::uint8_t reg, std::uint8_t x) {
    if (!write(reg, &x, 1))
      throw std::runtime_error("write failed");
  }
  std::uint16_t word(std::uint8_t reg) {
    std::uint8_t b[2];
    if (!read(reg, b, 2))
      throw std::runtime_error("read failed");
    return std::uint16_t((b[0] << 8) | b[1]);
  }
  void word(std::uint8_t reg, std::uint16_t x) {
    std::uint8_t b[2]{std::uint8_t(x >> 8), std::uint8_t(x)};
    if (!write(reg, b, 2))
      throw std::runtime_error("write failed");
  }
};
std::int8_t read_cb(std::uint8_t reg, std::uint8_t *data, std::uint32_t len, void *ctx) {
  return static_cast<Bus *>(ctx)->read(reg, data, len) ? 0 : -1;
}
std::int8_t write_cb(std::uint8_t reg, const std::uint8_t *data, std::uint32_t len, void *ctx) {
  return static_cast<Bus *>(ctx)->write(reg, data, len) ? 0 : -1;
}
void delay_cb(std::uint32_t us, void *) {
  std::this_thread::sleep_for(std::chrono::microseconds(us));
}
void check(int result) {
  if (result != 0)
    throw std::runtime_error("SensorAPI result " + std::to_string(result));
}
struct Device {
  std::string name, status = "unconfigured";
  Bus bus;
  int interval_ms;
  bool initialized = false;
  Clock::time_point due{}, retry{};
  std::uint64_t sequence = 0, errors = 0, samples = 0, missed_polls = 0;
  std::int64_t last_good = 0;
  bmi08_dev bmi{};
  bmp5_dev bmp{};
  bmp5_osr_odr_press_config bmp_cfg{};
  std::vector<Json> acquired;
  Device(std::string n, int ms) : name(std::move(n)), interval_ms(ms) {}
  void initialize() {
    if (!bus.open_bus())
      throw std::runtime_error("I2C unavailable");
    bmi.intf = BMI08_I2C_INTF;
    bmi.variant = BMI088_VARIANT;
    bmi.intf_ptr_accel = &bus;
    bmi.intf_ptr_gyro = &bus;
    bmi.read = read_cb;
    bmi.write = write_cb;
    bmi.delay_us = delay_cb;
    bmi.read_write_len = 32;
    if (name == "bmi088_accel") {
      check(bmi08a_init(&bmi));
      if (bmi.accel_chip_id != 0x1e)
        throw std::runtime_error("wrong accel chip ID");
      bmi.accel_cfg.power = BMI08_ACCEL_PM_ACTIVE;
      check(bmi08a_set_power_mode(&bmi));
      bus.byte(0x7d, 4);
      delay_cb(50000, nullptr);
      bmi.accel_cfg.odr = BMI08_ACCEL_ODR_100_HZ;
      bmi.accel_cfg.bw = BMI08_ACCEL_BW_NORMAL;
      check(bmi08a_set_meas_conf(&bmi));
      bus.byte(0x41, 3);
      check(bmi08a_get_meas_conf(&bmi));
      if (bmi.accel_cfg.odr != 8 || bmi.accel_cfg.bw != 10 || bmi.accel_cfg.range != 3 ||
          bus.byte(0x7d) != 4)
        throw std::runtime_error("accel config readback");
    } else if (name == "bmi088_gyro") {
      check(bmi08g_init(&bmi));
      if (bmi.gyro_chip_id != 0x0f)
        throw std::runtime_error("wrong gyro chip ID");
      bmi.gyro_cfg.power = BMI08_GYRO_PM_NORMAL;
      check(bmi08g_set_power_mode(&bmi));
      bmi.gyro_cfg.odr = BMI08_GYRO_BW_32_ODR_100_HZ;
      bmi.gyro_cfg.range = BMI08_GYRO_RANGE_2000_DPS;
      check(bmi08g_set_meas_conf(&bmi));
      bus.byte(0x3e, 0);
      bus.byte(0x3e, 0x80);
      check(bmi08g_get_meas_conf(&bmi));
      if (bmi.gyro_cfg.odr != 7 || bmi.gyro_cfg.range != 0 || bus.byte(0x11) != 0 ||
          bus.byte(0x3e) != 0x80)
        throw std::runtime_error("gyro config readback");
    } else if (name == "bmp581") {
      bmp.intf = BMP5_I2C_INTF;
      bmp.intf_ptr = &bus;
      bmp.read = read_cb;
      bmp.write = write_cb;
      bmp.delay_us = delay_cb;
      check(bmp5_init(&bmp));
      if (bmp.chip_id != 0x50)
        throw std::runtime_error("wrong BMP581 chip ID");
      check(bmp5_set_power_mode(BMP5_POWERMODE_STANDBY, &bmp));
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

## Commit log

2026-09-15 Initial plan
    [link-budget.xlsx]
2026-09-16 added carrier board pcb
    [PigeonCarrier.kicad_pcb, PigeonCarrier.kicad_sch]
2026-09-16 added CM5
    [CM5.kicad_sch, Cameras.kicad_sch, PigeonCarrier.kicad_sch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]
2026-09-19 add Ethernet sheet
    [Ethernet.kicad_sch, PigeonCarrier.kicad_sch]
2026-09-21 shortned readmes + start of power stuff
    [CM5.kicad_sch, PigeonCarrier.kicad_pcb, PigeonCarrier.kicad_sch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]
2026-09-30 add Pico SPI
2026-09-30 native SPI
2026-09-30 tidy SPI
2026-10-02 carrier progress
    [Camera_Regulators.kicad_sch, PigeonCarrier.kicad_pcb, PigeonCarrier.kicad_sch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]
2026-10-02 save ground station
    HOLD IT RIGHT THERE
2026-10-02 update ground receiver
2026-10-05 Update carrier schematics, parts library, and JLC rules
    [CM5.kicad_sch, Camera_Regulators.kicad_sch, Cameras.kicad_sch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]
2026-10-05 Replace remaining 1 uF X5R capacitors with X7R
    [Cameras.kicad_sch, Regulators.kicad_sch]
2026-10-05 Save latest carrier schematic edits
    [Cameras.kicad_sch, batt_5V_main.kicad_sch]
2026-10-05 update updategit statusgit status
    [Ethernet.kicad_sch, PigeonCarrier.kicad_pcb]
2026-10-05 Fix cached XT60 PCB model path
    [PigeonCarrier.kicad_pcb]
2026-10-10 finished rough layout
    [CM5.kicad_sch, Camera_Regulators.kicad_sch, Cameras.kicad_sch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]
2026-10-14 fix ground receiver
2026-10-16 Update carrier placement and vertical connector libraries
    Save the latest component placements and mechanical mounting changes. Include the vertical XT60/XT30 and camera connector symbols, footprints, redistributable CAD, licenses and documentation. Keep lo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
    Validation: ERC has zero findings. Native KiCad loading and netlist comparison confirm all 152 schematic components and 681 numbered pads agree. Full DRC could not complete because the KiCad CLI abor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
2026-10-20 fix camera recovery
2026-10-20 fix calibration recovery
2026-10-21 keep queued frames
    Advance the playback clock during catch-up without flushing the other camera. Keep full resets for timestamp jumps and cover both paths in CI.
2026-10-28 start yapogee s3
    Outline the ESP32 RF conversion board and its 5 V interface. Keep RF2052 and RFFC2072A open while drive levels and distortion are measured; add a reproducible cubic estimate with its limits.
2026-10-28 add kicad starter
    Create the empty Yapogee S3 project with portable shared-library paths. Record the characterized RF2052 bias setting and the gain and peak-headroom limits for the proposed 1-2 W PA target.
2026-10-28 calculate antenna link budget
    Use the owned TrueRC RHCP antenna pair and explicit receiver, loss and reserve assumptions. Clarify mixer-to-PA reference planes and document conditional QPSK and 8PSK free-space ranges.
2026-10-28 calculate crest factor
    Run the actual ESP32 pulse shaper and encoded frames: about 3.8 dB envelope PAPR in the 40 MS/s modes. Compare converter costs and a post-mixer driver while keeping digital calculations separate from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
2026-10-28 pick bare s3 parts
    Add the daughterboard BOM and checked local symbols and footprints for the bare ESP32-S3R8, high-side RFFC5072A converter, driver and power interfaces. Keep sourcing and review notes private; circuit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
2026-10-28 tidy bom formatting
    Use Unix line endings in the CSVs and remove whitespace from package files. Electrical data and pad geometry are unchanged.
2026-10-28 add standalone power and castellated interface
2026-10-28 refresh bypass capacitor sourcing
2026-10-28 adopt WROOM RF module and quiet 3V supply
2026-11-05 Save latest carrier schematic and connector edits
2026-11-05 Place and connect the Yapogee S3 landing on the carrier
2026-11-05 Save final Yapogee artwork and C41 ground routing
2026-11-06 Park the Yapogee landing for carrier placement
